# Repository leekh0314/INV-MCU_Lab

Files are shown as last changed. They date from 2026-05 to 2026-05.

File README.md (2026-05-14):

# INV-MCU_Lab

> **Gasoline Generator Digital Inverter Development Kit**  
> **汽油发电机数字逆变器开发套件**

INV-MCU_Lab 是一个面向工程学习、技术研究、项目复盘和方案验证的汽油发电机数字逆变器开源开发套件。

本项目围绕一套真实的汽油发电机数字逆变器软硬件系统展开，内容覆盖 MCU 控制软件、硬件参考资料、技术文档和测试报告，重点展示 MCU 在汽油发电机数字逆变器中的控制、采样、保护、调试和系统协同作用。

> **重要说明**  
> 虽然本项目名称中使用“开发套件”，但它不是一个建议直接量产的商业成品方案，也不是一个面向零基础用户的直接上电 DIY 套件。  
> 本项目涉及高压直流母线、230V 交流输出、大功率开关器件、汽油发动机系统和复杂保护逻辑。任何硬件复刻、上电测试或商业使用都必须由具备相关经验的工程人员完成完整验证。

---

## 1. Project Name / 项目名称

```text
English Name: INV-MCU_Lab
Chinese Name: 汽油发电机数字逆变器开发套件
```

项目名称含义：

- `INV`：Inverter，逆变器；
- `MCU`：Microcontroller Unit，微控制器；
- `Lab`：Laboratory，实验室 / 开发实验平台。

因此，INV-MCU_Lab 的核心定位是：

```text
一个用于学习、研究和理解汽油发电机数字逆变器 MCU 控制系统的开源开发套件。
```

---

## 2. Project Positioning / 项目定位

INV-MCU_Lab 不是一个简单的代码仓库，而是一个围绕真实工程项目整理出来的数字逆变器开发参考包。

它的重点不是鼓励用户直接复制一台可以量产的逆变器，而是帮助工程师理解以下问题：

- MCU 如何参与汽油发电机逆变器控制；
- PWM 如何通过查表、调制和占空比更新变成 SPWM；
- ADC 采样值如何换算成真实电压、电流和母线状态；
- 数字逆变器为什么需要软启动；
- 过压、欠压、过流、过载、过温等保护逻辑如何组织；
- 发电机运行状态、母线电压、逆变输出和 MCU 控制之间如何配合；
- MCU 软件如何与驱动电路、功率器件、采样电路和保护电路协同工作；
- 工程调试中如何通过串口输出、变量观测和故障码定位问题。

本项目更适合作为：

```text
工程学习资料
数字逆变器控制参考
MCU 控制软件架构样例
汽油发电机逆变器项目复盘资料
高压功率电子项目的系统级学习案例
```

---

## 3. Open Source Scope / 开源范围

本项目计划开源范围为：

```text
C. 软件 + 硬件 + 文档 + 测试报告
```

具体包括以下几类内容。

### 3.1 Firmware / 软件源码

软件部分主要包括：

- BAT32G139 MCU 工程源码；
- 系统初始化代码；
- PWM / SPWM 输出逻辑；
- ADC 采样与数据处理；
- 母线电压采样与补偿；
- 输出电压 / 输出电流采样处理；
- 软启动控制逻辑；
- 逆变器运行状态机；
- 保护状态机；
- 故障标志管理；
- 过压、欠压、过流、过载、短路、过温等保护逻辑；
- 串口调试输出；
- 工程参数配置文件；
- 与硬件平台相关的 BSP / Driver / App 层代码。

### 3.2 Hardware / 硬件资料

硬件部分根据整理情况可能包括：

- 原理图；
- PCB 文件；
- PCB 参考图；
- BOM；
- Gerber；
- 关键功率器件说明；
- 采样电路说明；
- 驱动电路说明；
- 辅助电源说明；
- 保护电路说明；
- 硬件接口定义。

### 3.3 Documentation / 技术文档

文档部分可能包括：

- 系统框图；
- 软件架构说明；
- 控制流程说明；
- SPWM 生成说明；
- ADC 采样换算说明；
- 软启动说明；
- 保护状态机说明；
- 故障码说明；
- 串口调试协议说明；
- 调试记录；
- 项目复盘笔记；
- 已知问题说明。

### 3.4 Test Report / 测试报告

测试报告部分可能包括：

- 型式试验报告；
- 调试测试记录；
- 关键波形记录；
- 负载测试记录；
- 故障保护测试记录；
- 工程验证记录。

由于测试报告、PDF、压缩包等文件可能较大，不建议全部直接提交到 Git 仓库主分支。大文件建议通过 GitHub Releases 发布。

---

## 4. What This Project Is / 本项目是什么

INV-MCU_Lab 是：

```text
一个汽油发电机数字逆变器 MCU 控制开发套件；
一个真实工程项目的开源学习版本；
一个用于理解数字逆变器软硬件协同的参考项目；
一个包含软件、硬件、文档和测试资料的系统级学习案例。
```

本项目可以帮助使用者学习：

- 汽油发电机逆变器的基本系统构成；
- MCU 在逆变器中的作用；
- SPWM 与功率桥之间的关系；
- ADC 采样与实际电气量之间的换算；
- 软件保护逻辑如何与硬件保护配合；
- 故障标志如何设计；
- 状态机如何组织；
- 串口调试如何服务于真实项目排障；
- 软件、硬件、功率器件和测试方法之间的关系。

---

## 5. What This Project Is Not / 本项目不是什么

为了避免误解，INV-MCU_Lab 明确不是以下内容。

### 5.1 不是直接量产方案

本项目虽然包含软件、硬件、文档和测试报告，但开源版本仍然仅作为学习、研究和工程参考使用。

不建议未经完整验证、安规评估、EMC 测试、可靠性测试、长时间负载测试和生产一致性验证，直接用于商业量产。

### 5.2 不是零基础 DIY 套件

本项目涉及高压、大功率和汽油发电机系统，不适合没有电力电子经验、没有隔离测试设备、没有示波器和差分探头经验的用户直接复刻或上电。

### 5.3 不是安全认证过的产品

本项目本身不代表已经通过任何国家或地区的安全认证、EMC 认证、能效认证、环保认证或产品合规认证。

### 5.4 不是商业技术支持服务

本项目以开源资料形式提供。作者不承诺提供商业级技术支持、定制开发、远程调试、量产问题兜底或售后服务。

### 5.5 不是第三方软件 / 工具的再分发仓库

本项目不会提供商业软件安装包、破解工具、注册机、授权文件或未经许可的第三方资料。

如果项目需要 Keil、芯片 Pack、串口工具、VOFA+、烧录工具等，请使用者自行从官方渠道获取。

---

## 6. Commercial Use Boundary / 商用边界

本项目允许用于：

```text
学习
研究
技术交流
工程参考
个人实验
非商业项目验证
```

本项目不建议直接用于：

```text
商业量产
客户项目直接交付
未验证的整机产品
面向普通用户销售的成品设备
绕过安全认证的商业应用
```

如果你希望将本项目用于商业产品、批量生产或客户项目，请务必自行完成以下工作：

- 完整硬件设计复核；
- 软件代码审查；
- 控制参数重新标定；
- 采样系数重新校准；
- 保护阈值重新确认；
- 功率器件选型验证；
- 热设计验证；
- 安规设计；
- EMC 测试；
- 高低温测试；
- 老化测试；
- 满载和过载测试；
- 短路和故障注入测试；
- 发动机实际工况测试；
- 生产测试流程设计；
- 不同国家和地区的法规合规评估。

作者不对任何直接或间接商业使用结果承担责任。

---

## 7. Technical Scope / 技术范围边界

本项目重点关注以下内容：

```text
MCU 控制逻辑
数字逆变器软件架构
SPWM 生成
ADC 采样与换算
母线电压处理
软启动控制
保护状态机
故障标志管理
串口调试
汽油发电机逆变器系统级理解
```

本项目不重点解决以下问题：

```text
最终量产设计
批量生产工艺
安规认证
EMC 认证
整机结构设计
散热器批量制造
生产测试工装
商业售后体系
不同地区法规认证
直接可销售成品设计
```

---

## 8. Hardware Safety Boundary / 硬件安全边界

本项目涉及的硬件系统可能包含：

- 高压直流母线；
- 230V AC 逆变输出；
- 大功率 MOSFET / IGBT / 驱动电路；
- 电压采样和电流采样电路；
- 汽油发动机发电绕组；
- 辅助电源；
- 继电器、风扇、保护电路；
- 散热器和高温功率器件。

错误操作可能导致：

- 触电；
- 功率器件炸裂；
- PCB 烧毁；
- 火灾；
- 发电机损坏；
- 测试仪器损坏；
- 人身伤害。

使用者在任何上电测试前，必须自行准备并确认：

- 隔离电源；
- 差分探头；
- 示波器安全接法；
- 限流措施；
- 保险丝或断路保护；
- 电子负载或合适负载；
- 绝缘防护；
- 紧急断电措施；
- 高压测试安全区域；
- 足够的电力电子和嵌入式调试经验。

---

## 9. Suggested Audience / 适合人群

本项目适合：

- 嵌入式工程师；
- 电力电子工程师；
- 汽油发电机逆变器研发人员；
- 想学习 SPWM、ADC 采样、保护状态机的工程人员；
- 想通过真实项目理解 MCU 如何控制功率硬件的学习者；
- 对数字逆变器控制软件架构感兴趣的人；
- 希望研究汽油发电机逆变器系统构成的人。

本项目不适合：

- 完全没有高压电路经验的初学者；
- 只想找一个直接复制量产方案的人；
- 没有示波器、隔离设备、负载设备的用户；
- 不理解高压大功率风险的用户；
- 希望绕过工程验证直接销售产品的人。

---

## 10. Main Features / 主要功能模块

当前项目重点覆盖以下功能模块：

- MCU system initialization；
- PWM / SPWM generation；
- ADC sampling；
- DC bus voltage processing；
- AC output voltage processing；
- AC output current processing；
- soft-start control；
- inverter state machine；
- protection state machine；
- fault flag management；
- overload protection logic；
- short-circuit protection logic；
- over-voltage and under-voltage protection logic；
- UART debug output；
- engineering parameter configuration；
- generator inverter system analysis notes。

---

## 11. Repository Structure / 仓库目录结构

建议仓库结构如下：

```text
INV-MCU_Lab/
│
├─ firmware/
│  └─ INV-MCU_Lab/
│     ├─ App/
│     ├─ BSP/
│     ├─ Driver/
│     ├─ User/
│     └─ README.md
│
├─ hardware/
│  ├─ schematic/
│  ├─ pcb/
│  ├─ bom/
│  ├─ gerber/
│  └─ README.md
│
├─ docs/
│  ├─ architecture/
│  ├─ debug_notes/
│  ├─ test_report/
│  └─ README.md
│
├─ tools/
│  ├─ scripts/
│  └─ README.md
│
├─ release_assets/
│  └─ local_only_not_committed/
│
├─ README.md
├─ LICENSE
├─ NOTICE.md
├─ DISCLAIMER.md
└─ .gitignore
```

目录说明：

- `firmware/`：MCU 源码、Keil 工程、驱动层和应用层代码；
- `hardware/`：原理图、PCB、BOM、Gerber 和硬件说明；
- `docs/`：系统说明、调试记录、框图、测试报告说明和技术文档；
- `tools/`：工具使用说明和可公开脚本；
- `release_assets/`：本地临时目录，不提交到 Git 仓库，用于整理大 PDF、压缩包和发布附件。

---

## 12. Release Downloads / 发布附件下载

Large files, tool packages and release assets are available from GitHub Releases.

大文件、工具包和发布附件请从 GitHub Releases 页面下载。

Release page:

```text
https://github.com/leekh0314/INV-MCU_Lab/releases
```

---

## 13. Development Environment / 开发环境

当前项目可能涉及以下开发环境：

```text
MCU: BAT32G139
IDE: Keil MDK
Language: C
Application: 3KW / 230V gasoline generator digital inverter
```

具体编译器版本、芯片 Pack、工程配置和烧录说明，应在 `firmware/BAT32G139/README.md` 中进一步说明。

---

## 14. Build and Debug / 编译与调试

建议后续在固件目录中补充以下内容：

- Keil 工程打开方法；
- 编译器版本要求；
- 芯片 Pack 安装说明；
- 下载器 / 烧录器说明；
- 串口调试波特率；
- 串口调试协议；
- 调试变量说明；
- 常见编译错误；
- 常见硬件调试注意事项；
- 上电前检查清单。

---

## 15. Documentation Plan / 文档计划

后续文档可以按以下主题逐步补充：

```text
01_system_overview.md
02_pwm_spwm.md
03_adc_sampling.md
04_soft_start.md
05_protection_state_machine.md
06_uart_debug.md
07_fault_code.md
08_hardware_overview.md
09_test_report_notes.md
10_known_issues.md
```

---

## 16. Known Risks / 已知风险

本项目至少存在以下风险：

- 不同硬件版本之间参数可能不完全一致；
- 不同功率器件、采样电阻、母线电压和驱动电路会影响控制参数；
- 软件保护阈值必须结合实际硬件重新校准；
- ADC 换算系数需要根据实际采样电路确认；
- PWM 死区、驱动逻辑和功率器件参数必须严格匹配；
- 直接照搬源码可能导致输出异常、器件损坏或安全事故；
- 文档和代码可能存在未完全同步的地方；
- 测试报告中的结论不能自动等同于所有复刻硬件都能达到相同结果；
- 本项目不能替代完整的产品认证和量产验证流程。

---

## 17. Contribution / 贡献方式

欢迎提交以下类型的贡献：

- 文档修正；
- 注释补充；
- 编译问题修复；
- 模块化改进；
- 调试记录补充；
- 框图和流程图补充；
- 安全警告补充；
- issue 反馈；
- 代码可读性改进。

不建议提交以下内容：

- 商业软件安装包；
- 破解工具；
- 未授权数据手册；
- 与项目无关的大文件；
- 未经验证的危险硬件修改；
- 删除安全保护逻辑的修改；
- 绕过保护机制的修改；
- 不说明风险的参数改动。

---

## 18. License / 开源协议

软件源码：MIT License
硬件资料：CERN-OHL-P
文档和测试报告：CC BY 4.0

---

## 19. Disclaimer / 免责声明

This project is provided for learning, research and engineering reference only.

本项目仅用于学习、研究和工程参考。

The author does not guarantee that this project is suitable for direct production, commercial use or direct hardware replication.

作者不保证本项目适合直接量产、商业使用或直接硬件复刻。

This project involves high voltage, high current, power inverter hardware and gasoline generator systems. Incorrect use may cause electric shock, fire, equipment damage or personal injury.

本项目涉及高压、大电流、功率逆变硬件和汽油发电机系统。错误使用可能导致触电、火灾、设备损坏或人身伤害。

Any use of this project is at your own risk.

使用本项目所产生的一切风险由使用者自行承担。

---

## 20. Recommended First Reading Order / 推荐阅读顺序

如果你是第一次接触本项目，建议按以下顺序阅读：

```text
1. README.md
2. DISCLAIMER.md
3. docs/architecture/system_overview.md
4. firmware/BAT32G139/README.md
5. docs/debug_notes/
6. hardware/README.md
7. docs/test_report/
```

---

## 21. Project Status / 项目状态

当前项目处于开源整理阶段。

后续将逐步补充：

- 更清晰的代码结构说明；
- 系统框图；
- SPWM 控制说明；
- ADC 采样说明；
- 保护状态机说明；
- 串口调试协议说明；
- 硬件资料整理；
- 测试报告和调试记录；
- Release 附件说明；
- 上电测试安全清单。

---

## 22. Final Note / 最后说明

INV-MCU_Lab 的核心价值不是鼓励用户直接复制一台逆变器，而是通过一套接近真实工程的软硬件资料，帮助工程师理解：

```text
MCU 如何参与汽油发电机数字逆变器的控制、采样、保护、调试和系统协同。
```

如果你只是想学习数字逆变器的 MCU 控制逻辑，本项目可以作为参考。

如果你想基于本项目制作真实硬件或商业产品，请务必重新完成完整的工程验证、安全评估和合规测试。

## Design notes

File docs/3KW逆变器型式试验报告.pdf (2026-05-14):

第1页 共 14 页

# 型 式 试 验 报 告

型式试验报告编号：
型式试验报总页数： 共 13 页

产 品 名 称：逆变器

产 品 型 号：

生 产 单 位：

编 | 制：
审 | 核：
批 | 准：
签发日期： | 年 | 月 | 日

第2页 共 14 页

# 检验报告

产品名称 | 逆变器 | 型 号 | 3KW-230V-50HZ | 备 注
检验目的 | 评价逆变器外观
检验项目 | 外观检查
检验依据 | 逆变器通用型式试验基准
技 术 要 求 | 逆变器的外表面清洁、标志清晰、封装完好。
检 验 方 法 | 目测

检 验 验 结 果

项 目 | 技术要求 | 1# | 2# | 3# | 4# | 5#
外 观 | 逆变器的外表面清洁、标志 清晰、封装完好 | OK | OK

第3页 共 14 页

# 检验报告

产品名称 | 逆变器 | 型 号 | 3KW-230V-50HZ | 备 注
检验目的 | 检查逆变器绝缘电阻
检验项目 | 绝缘电阻检查
检验依据 | 逆变器通用型式试验基准
技 术 要 求 | 逆变器外壳与交流输出端能承受 1500VAC 电压 5 秒不损坏且漏电流小于 5mA。
检 验 方 法 | 使用专用绝缘电阻耐压测试仪，电压调制 1500VAC，黑色表笔与逆变器外壳连接，红色表笔与逆 变器交流输出连接，按下测试按钮测试

检 验 验 结 果

项 目 | 技术要求 | 1# | 2# | 3# | 4# | 5#
绝缘电阻 | 漏电流≤5mA

第4页 共 14 页

# 检验报告

产品名称 | 逆变器 | 型 号 | 3KW-230V-50HZ | 备 注
检验目的 | 考核逆变器调速性能是否在技术要求范围内
检验项目 | 调速性能检查
检验依据 | 逆变器通用型式试验基准
技 术 要 求 | 1. 逆变器性能测试在常温环境条件下进行： 2. 逆变器能应符合下表的规定：
项 目 | 技术要求
空载转速（节能模式） | 2800±100r/min
空载转速（非节能模式） | 3400±100r/min
满载转速 | 3600±100r/min

检
验
方
法

将逆变器与适配发电机组连接，按上述技术要求进行检测。

检
验
结
果
项 目 | 技术要求 | 1# | 2#
空载转速（节能模式） | 2850±100r/min | 2840-2870 | 2840-2870
空载转速（非节能模式） | 3400±100r/min | 3370-3390 | 3370-3380
满载转速 | 3450±100r/min | 3450-3480 | 3450-3470

第5页 共 14 页

# 试验报告

产品名称 | 逆变器 | 型 号 | 3KW-230V-50HZ | 备 注
试验目的 | 考核逆变器负载能力
试验项目 | 带阻性负载
试验依据 | 逆变器通用型式试验基准

技 术 要 求

负载 比例 | 视在功率 （VA） | 测试标准
最高电 压 V | 最低电 压 V | 电流 A | 功率因素 | 频率（HZ） | THD ％
0％ | 0 | 233 | 229 | 0 | 1 | 50.0±0.1 | ≤3%
25％ | 800 | 233 | 229 | 3.5±0.5 | 1 | 50.0±0.1 | ≤3%
50％ | 1600 | 232 | 228 | 7±0.5 | 1 | 50.0±0.1 | ≤3%
75％ | 2400 | 231 | 227 | 10.5±0.5 | 1 | 50.0±0.1 | ≤3%
100％ | 3200 | 230 | 226 | 14±0.5 | 1 | 50.0±0.1 | ≤3%
110％ | 3520
试 验 方 法 | 检验方法：将安装有测试逆变器的发电机组与负载柜连接，使用相应设备测试，记录数据

试
验
结
果
负载 比例 | 视在功率 （VA） | 测试标准 | 功率 因数 | 测试结果
最高 电压 234V | 最低 电压 226V | 电流 A | | 最高电 压 V | 最低 电压 V | 电 流 A | 频率 （HZ） | THD ％
0％ | | 233 | 229 | 0 | 1 | 231.1 | 231
25％ | 800 | 233 | 229 | 3.5± 0.5 | 1 | 231.2 | 231.1 | 3.4 | 50.04
50％ | 1600 | 232 | 228 | 7± 0.5 | 1 | 229.9 | 229.8 | 6.9 7 | 50.03
75％ | 2400 | 231 | 227 | 10.5 ±0.5 | 1 | 228.4 | 228.3 | 10. 73 | 50.03
100％ | 3200 | 230 | 226 | 14± 0.5 | 1 | 226.5 | 226.4 | 14. 28 | 50.03
110％ | 3520

第6页 共 14 页

# 试验报告

产品名称 | 逆变器 | 型 号 | 3KW-230V-50HZ | 备 注
试验目的 | 考核逆变器负载能力
试验项目 | 带非线性负载
试验依据 | 逆变器通用型式试验基准

技 术 要 求

负载 比例 | 视在功率 （VA） | 测试标准
最高电 压 V | 最低电 压 V | 电流 A | 功率因素 | 频率（HZ） | THD ％
0％ | 0 | 233 | 229 | 0 | 0.8 | 50.0±0.1 | ≤6%
25％ | 800 | 233 | 229 | 3.5±0.5 | 0.8 | 50.0±0.1 | ≤6%
50％ | 1600 | 232 | 228 | 7±0.5 | 0.8 | 50.0±0.1 | ≤6%
75％ | 2400 | 231 | 227 | 10.5±0.5 | 0.8 | 50.0±0.1 | ≤6%
100％ | 3200 | 230 | 226 | 14±0.5 | 0.8 | 50.0±0.1 | ≤6%
110％ | 3520
试 验 方 法 | 检验方法：将安装有测试逆变器的发电机组与负载柜连接，使用相应设备测试，记录数据
试 验 结 果 | | 负载 比例 | 视在功率 （VA） | 测试标准 | 功率 因数 | 测试结果
最高 电压 234V | 最低 电压 226V | 电流 A | | 最高电 压 V | 最低 电压 V | 电 流 A | 频率 （HZ） | THD ％
0％ | | 233 | 229 | 0 | 0.8 | 231.1 | 231
25％ | 800 | 233 | 228 | 3.5± 0.5 | 0.8 | 229.2 | 229.1 | 3.6 5 | 50.04
50％ | 1600 | 232 | 227 | 7± 0.5 | 0.8 | 228.2 | 228.1 | 6.9 2 | 50.03
75％ | 2400 | 231 | 226 | 10.5 ±0.5 | 0.8 | 227.4 | 227.3 | 10. 57 | 50.03
100％ | 3200 | 230 | 225 | 14± 0.5 | 0.8 | 226.1 | 226.0 | 14. 32 | 50.03
110％ | 3520

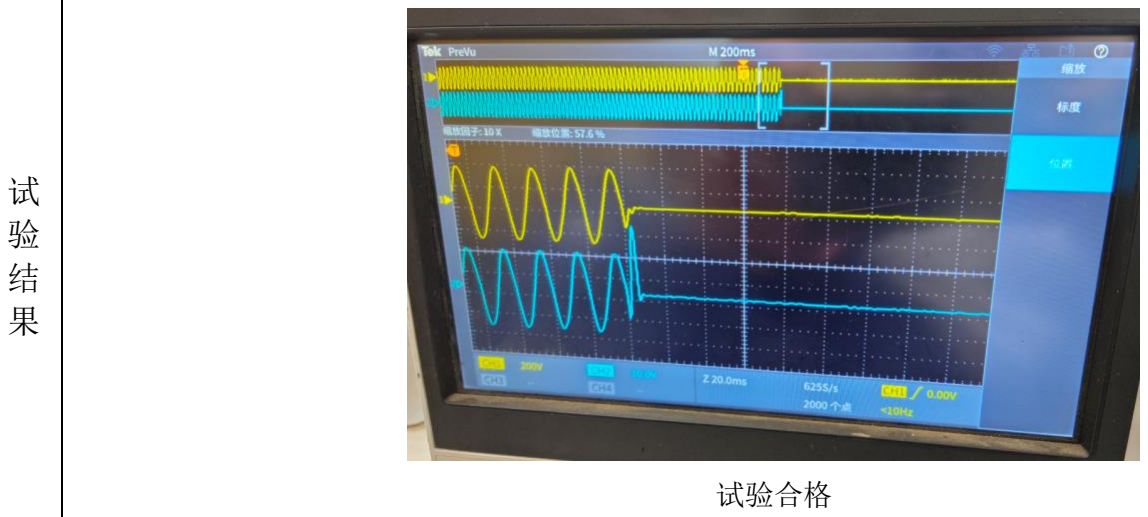
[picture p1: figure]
试验合格

第7页 共 14 页

# 试验报告

产品名称 | 逆变器 | 型 号 | 3KW-230V-50HZ | 备 注
试验目的 | 考核逆变器冲击性能
试验项目 | 短路试验
试验依据 | 逆变器通用型式试验基准
技 术 要 求 | 逆变器在额定负载下进行输出短路，连续短路 100 测逆变器无损坏
试 验 方 法 | 将测试逆变器机组与负载连接，短路 2S,断开 10S，断开过程复位逆变器，连续重复 100 次

第8页 共 14 页

# 试验报告

产品名称 | 逆变器 | 型 号 | 3KW-230V-50HZ | 备 注
试验目的 | 考核逆变器耐温性能
试验项目 | 高温试验
试验依据 | 逆变器通用型式试验基准
技 术 要 求 | 将逆变器升温至 75℃，在额定负载下工作，工作过程维持温度 75℃，连续运行 10 小时，逆变器 不损坏
试 验 方 法 | 将测试逆变器机组与负载柜连接，将逆变器升温至 75℃，加额定负载运行，过程中人为控制逆变 器外壳温度为 75℃，连续运行 10 小时，记录结果
试 验 结 果 | 高温后产品性能符合要求，试验合格

第9页 共 14 页

产品名称 | 逆变器 | 型 号 | 3KW-230V-50HZ | 备 注
试验目的 | 考核逆变器耐温性能
试验项目 | 低温试验
试验依据 | 逆变器通用型式试验基准
技 术 要 求 | 逆变器在-25℃环境下静置不少于 48 小时，逆变器能正常启动，启动后加额定负载正常工作，无 损坏
试 验 方 法 | 将逆变器在-25℃环境下静置不少于 48 小时，逆变器与机组连接，启动机组记录启动结果，加额 定负载，记录带载结果
试 验 结 果 | 试验后逆变器启动正常，试验合格

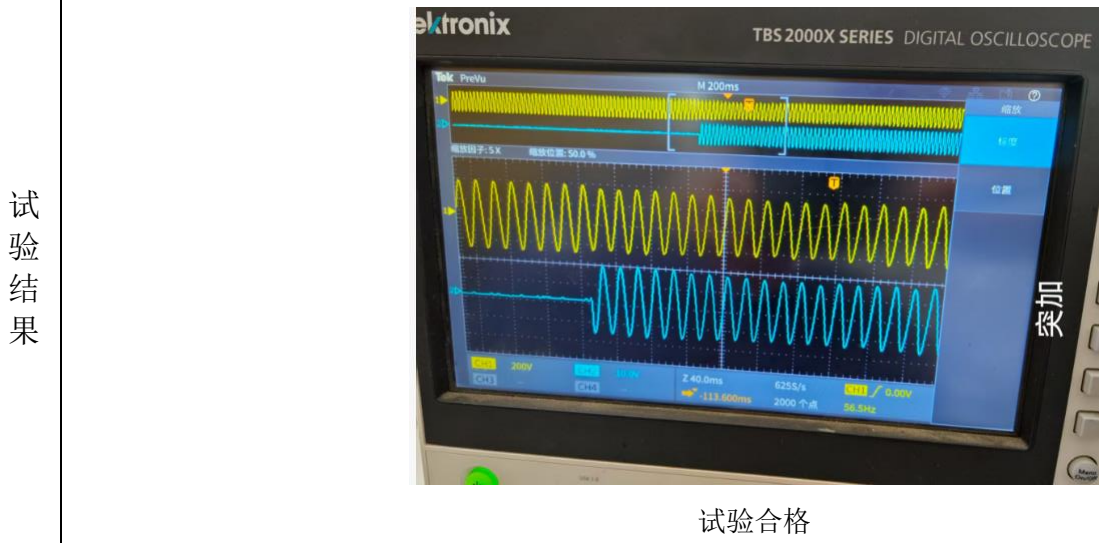
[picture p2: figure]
试验合格

第10页 共 14 页

产品名称 | 逆变器 | 型 号 | 3KW-230V-50HZ | 备 注
试验目的 | 考核逆变器冲击性能
试验项目 | 突加阻性负载试验
试验依据 | 逆变器通用型式试验基准
技 术 要 求 | 逆变器与机组连接，并于额定负载连接，突加额定阻性负载，逆变器波形正常，试验结束后逆变 器无故障，试验过程中逆变器无误保护。
试 验 方 法 | 逆变器与机组连接，并于额定负载连接，突加额定阻性负载，试验次数 100 次

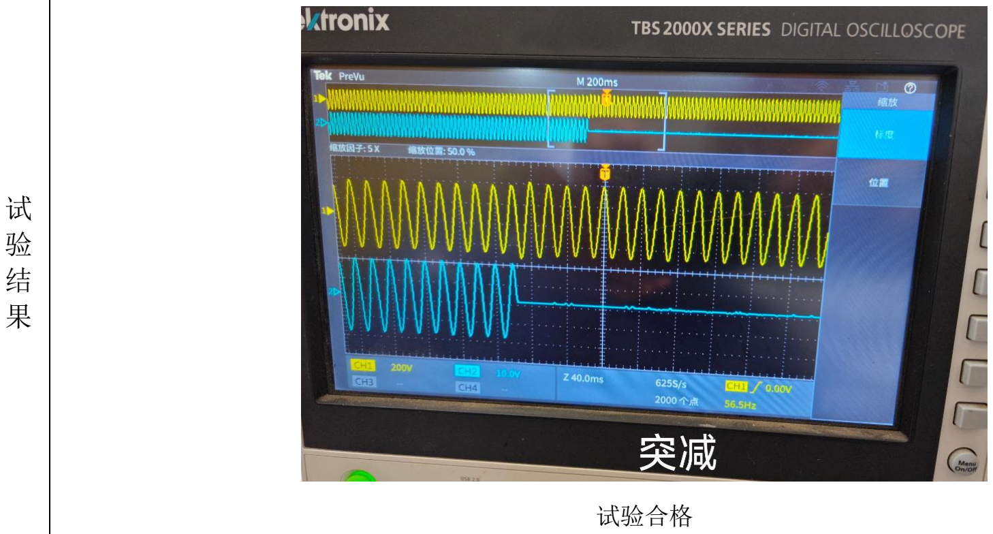
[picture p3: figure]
试验合格

第11页 共 14 页

产品名称 | 逆变器 | 型 号 | 3KW-230V-50HZ | 备 注
试验目的 | 考核逆变器冲击性能
试验项目 | 突减阻性负载试验
试验依据 | 逆变器通用型式试验基准
技 术 要 求 | 逆变器与机组连接，并于额定负载连接，逆变器满载阻性负载运行，突减去全部负载，逆变器波 形正常，试验结束后逆变器无故障，试验过程中逆变器无误保护。
试 验 方 法 | 逆变器与机组连接，并于额定负载连接并加载，逆变器满载阻性负载运行，突减负载，试验次数 100 次

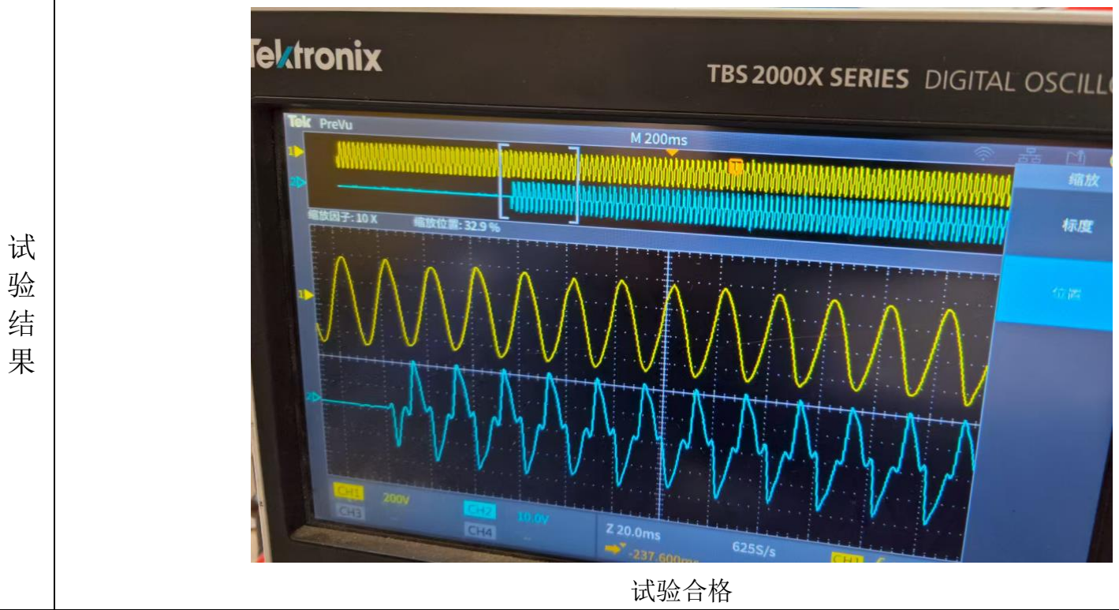
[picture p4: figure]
试验合格

第12页 共 14 页

产品名称 | 逆变器 | 型 号 | 3KW-230V-50HZ | 备 注
试验目的 | 考核逆变器冲击性能
试验项目 | 突加非线性负载试验
试验依据 | 逆变器通用型式试验基准
技 术 要 求 | 逆变器与机组连接，并于额定负载连接，突加额定非线性性负载，逆变器波形正常，试验结束后 逆变器无故障，试验过程中逆变器无误保护。
试 验 方 法 | 逆变器与机组连接，并于额定负载连接，突加额定非线性负载，试验次数 100 次

第13页 共 14 页

产品名称 | 逆变器 | 型 号 | 3KW-230V-50HZ | 备 注
试验目的 | 考核逆变器冲击性能
试验项目 | 突减非线性负载试验
试验依据 | 逆变器通用型式试验基准
技 术 要 求 | 逆变器与机组连接，并于额定负载连接，逆变器满载非线性负载运行，突减去全部负载，逆变器 波形正常，试验结束后逆变器无故障，试验过程中逆变器无误保护。
试 验 方 法 | 逆变器与机组连接，并于额定负载连接并加载，逆变器满载非线性负载运行，突减负载，试验次 数 100 次

试
验
结
果

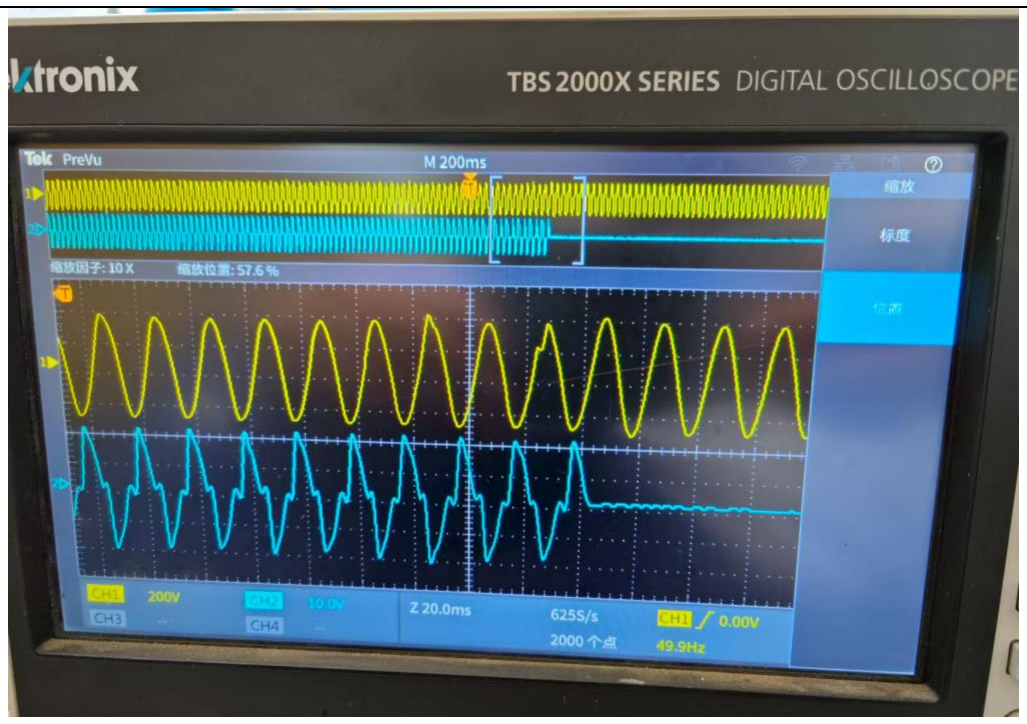
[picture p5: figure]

试验合格

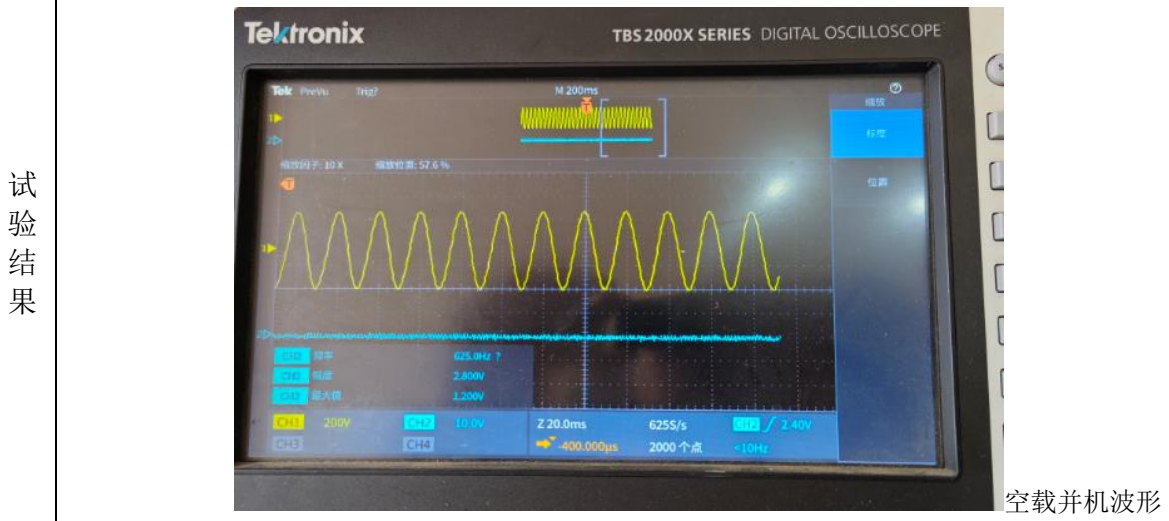
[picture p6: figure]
空载并机波形

第14页 共 14 页

产品名称 | 逆变器 | 型 号 | 3KW-230V-50HZ | 备 注
试验目的 | 考核逆变器并机性能
试验项目 | 并机环流带载试验
试验依据 | 逆变器通用型式试验基准
技 术 要 求 | 将两台逆变器连接在一起，先启动一台，启动的正常工作后，启动另一台，两台正常启动后，任 意一台无保护现象，并机环流小于 0.5A，总负载能力不低于两个单台相加负载综合的 93％
试 验 方 法 | 按上述技术要求连接逆变器，正常工作后记录数据

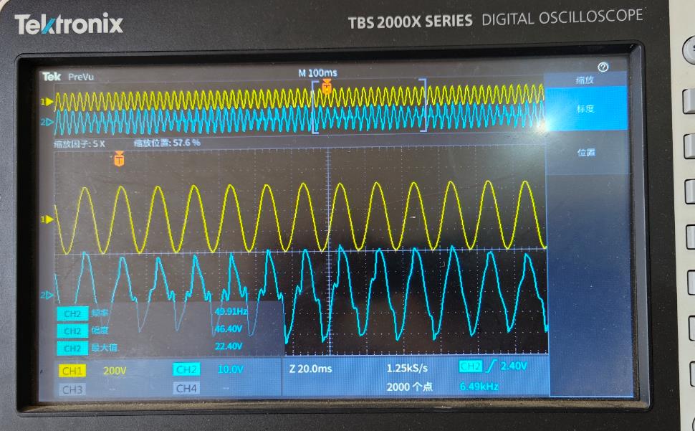
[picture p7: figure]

第15页 共 14 页

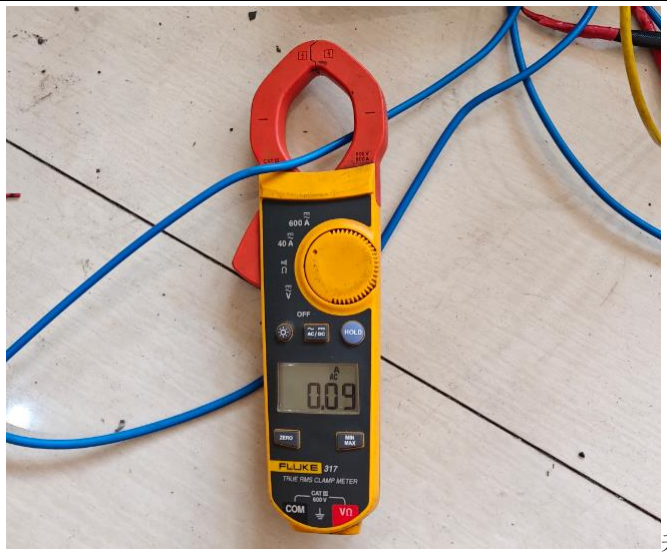
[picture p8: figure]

并机环流

并机满载波形

黄色为电压波形，绿色为电流波形
并机合格

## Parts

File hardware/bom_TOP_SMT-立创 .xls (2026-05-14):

立创商城BOM报价单
BOM配单编号： |  |  |  |  | 上传时间： |  |  |  | 1.名称释义：MPQ--最小包装量；MOQ--最小起订量； 2.匹配结果为实时查询结果，库存和价格可能会有波动。如超过24小时，请在立创商城重新匹配后下单； 3.订货商品的价格仅供参考，请提交订单后确定。 4.如有部分物料未能成功匹配，需要整单购买，请联系商城客服。
BOM名称：bom_TOP_SMT |  |  |  |  | 采购套数：
商品总价: 注：报价单总价不含待确认和无法匹配项 |  |  |  |  | 网址：
原始需求 |  |  |  |  |  |  |  |  | 匹配结果 |  |  |  |  |  |  | 订单满足
原始型号 | 原始品牌 | Footprint | Comment | C编码 | No. | Description | Designator | Quantity | 匹配结果 | 商品名称 | 型号 | 品牌 | 封装 | 参数 | 目录 | 商品编号 | 商品链接 | 渠道 | 交期 | MOQ | MPQ | 库存 | 购买数量 | 单价(RMB) | 关税税率 | 小计(RMB) | 备注
 |  | C0603 | 105 |  | 1 | 贴片 无极性电容 | C1, C6, C33, C83 | 4 | 系统匹配 | 1uF ±10% 50V | CGA0603X5R105K500JT | HRE(芯声) | 0603 | 容值：1uF 精度：±10% 额定电压：50V 温度系数：X5R | 电容 | C6119852 | https://item.szlcsc.com/7062558.html | 现货 | 4小时内发货 | 50 | 4000 | 6082200 | 50 | 0.0501 | 0 | 2.51
 |  | 1206C | 102/1KV |  | 2 | 贴片 无极性电容 | C3, C62, C63, C64, C66, C67, C68 | 7 | 系统匹配 | 1nF ±10% 1kV | 1206B102K102NT | FH(风华) | 1206 | 容值：1nF 精度：±10% 额定电压：1kV 温度系数：X7R | 电容 | C1941 | https://item.szlcsc.com/2293.html | 现货 | 4小时内发货 | 50 | 3000 | 939450 | 100 | 0.0632 | 0 | 6.32
 |  | C0603 | 104 |  | 3 | 贴片 无极性电容 | C4, C5, C8, C10, C11, C12, C16, C17, C23, C30, C36, C44, C46, C50, C71, C79, C84 | 17 | 系统匹配 | 100nF ±10% 50V | CGA0603X7R104K500JT | HRE(芯声) | 0603 | 容值：100nF 精度：±10% 额定电压：50V 温度系数：X7R | 电容 | C6119867 | https://item.szlcsc.com/7062573.html | 现货 | 4小时内发货 | 100 | 4000 | 19535300 | 200 | 0.0161 | 0 | 3.22
 |  | C0603 | 471/50V |  | 5 | 贴片 无极性电容 | C13 | 1 | 系统匹配 | 470pF ±10% 50V | 0603B471K500NT | FH(风华) | 0603 | 容值：470pF 精度：±10% 额定电压：50V 温度系数：X7R | 电容 | C1620 | https://item.szlcsc.com/1972.html | 现货 | 4小时内发货 | 100 | 4000 | 800800 | 100 | 0.0208 | 0 | 2.08
 |  | C0603 | 226 |  | 6 | 贴片 无极性电容 | C14, C25, C27, C32 | 4 | 系统匹配 | 22uF ±20% 16V | CGA0603X5R226M160JT | HRE(芯声) | 0603 | 容值：22uF 精度：±20% 额定电压：16V 温度系数：X5R | 电容 | C6119868 | https://item.szlcsc.com/7062574.html | 现货 | 4小时内发货 | 10 | 4000 | 500490 | 50 | 0.242 | 0 | 12.10
 |  | C0603 | 102 |  | 7 | 贴片 无极性电容 | C15, C18, C20, C21, C22, C26, C45, C49, C51, C54 | 10 | 系统匹配 | 1nF ±10% 50V | CC0603KRX7R9BB102 | YAGEO(国巨) | 0603 | 容值：1nF 精度：±10% 额定电压：50V 温度系数：X7R | 电容 | C100040 | https://item.szlcsc.com/101254.html | 现货 | 4小时内发货 | 100 | 4000 | 9242300 | 100 | 0.0151 | 0 | 1.51
 |  | C0603 | 103 |  | 8 | 贴片 无极性电容 | C19, C24, C28, C31, C37, C42, C47, C82 | 8 | 系统匹配 | 10nF ±10% 50V | CC0603KRX7R9BB103 | YAGEO(国巨) | 0603 | 容值：10nF 精度：±10% 额定电压：50V 温度系数：X7R | 电容 | C100042 | https://item.szlcsc.com/101256.html | 现货 | 4小时内发货 | 100 | 4000 | 4069100 | 100 | 0.0155 | 0 | 1.55
 |  | C0603 | 20pF |  | 9 | 贴片 无极性电容 | C34, C41 | 2 | 系统匹配 | 20pF ±5% 50V | CC0603JRNPO9BN200 | YAGEO(国巨) | 0603 | 容值：20pF 精度：±5% 额定电压：50V 温度系数：NP0 | 电容 | C105621 | https://item.szlcsc.com/106836.html | 现货 | 4小时内发货 | 100 | 4000 | 4229800 | 100 | 0.0189 | 0 | 1.89
 |  | C0603 | 101 |  | 10 | 贴片 无极性电容 | C35, C43, C53, C55 | 4 | 系统匹配 | 100pF ±5% 50V | CC0603JRNPO9BN101 | YAGEO(国巨) | 0603 | 容值：100pF 精度：±5% 额定电压：50V 温度系数：NP0 | 电容 | C14665 | https://item.szlcsc.com/15333.html | 现货 | 4小时内发货 | 100 | 4000 | 8312100 | 100 | 0.0175 | 0 | 1.75
 |  | C0603 | 106 |  | 11 | 贴片 无极性电容 | C40 | 1 | 系统匹配 | 10uF ±10% 10V | CGA0603X5R106K100JT | HRE(芯声) | 0603 | 容值：10uF 精度：±10% 额定电压：10V 温度系数：X5R | 电容 | C6119842 | https://item.szlcsc.com/7062548.html | 现货 | 4小时内发货 | 50 | 4000 | 2849500 | 50 | 0.05 | 0 | 2.50
 |  | 1206C | 103/50V |  | 12 | 贴片 无极性电容 | C58, C59, C60 | 3 | 系统匹配 | 10nF ±10% 50V | FCC1206B103K500DT | FOJAN(富捷) | 1206 | 容值：10nF 精度：±10% 额定电压：50V 温度系数：X7R | 电容 | C5137623 | https://item.szlcsc.com/5747075.html | 现货 | 4小时内发货 | 50 | 4000 | 651600 | 50 | 0.0655 | 0 | 3.28
 |  | 1206C | 471/1KV |  | 13 | 贴片 无极性电容 | C61, C65, C75, C76 | 4 | 系统匹配 | 470pF ±10% 1kV | 1206B471K102NT | FH(风华) | 1206 | 容值：470pF 精度：±10% 额定电压：1kV 温度系数：X7R | 电容 | C9189 | https://item.szlcsc.com/9714.html | 现货 | 4小时内发货 | 50 | 3000 | 216100 | 50 | 0.080586 | 0 | 4.03
 |  | 1206C | 225 |  | 14 | 贴片 无极性电容 | C70, C72, C73, C74, C77, C78, C80, C81 | 8 | 系统匹配 | 2.2uF ±10% 100V | CC1206KKX7R0BB225 | YAGEO(国巨) | 1206 | 容值：2.2uF 精度：±10% 额定电压：100V 温度系数：X7R | 电容 | C577211 | https://item.szlcsc.com/604702.html | 现货 | 4小时内发货 | 10 | 2000 | 310530 | 10 | 0.3512 | 0 | 3.51
 |  | SMA - AK | SS1200 |  | 15 | 贴片 二极管 | D1, D2, D4, D5, D7, D9, D26 | 7 | 系统匹配 | 电压:200V 电流:1A | SS1200 | MDD(辰达半导体) | SMA(DO-214AC) | 二极管配置：独立式 正向压降(Vf)：900mV@1A 直流反向耐压(Vr)：200V 整流电流：1A 反向电流(Ir)：100uA@200V 工作结温范围：-55℃~+150℃ 非重复峰值浪涌电流 (Ifsm)：25A | 二极管 | C64988 | https://item.szlcsc.com/66058.html | 现货 | 4小时内发货 | 20 | 5000 | 198280 | 80 | 0.20304 | 0 | 16.24
 |  | SMA - AK | US2M |  | 16 | 贴片 二极管 | D3, D6 | 2 | 系统匹配 | 耐压:1000V 电流:2A 反向恢复时间：75ns | US2M | R+O(宏嘉诚) | SMA(DO-214AC) | 二极管配置：1个独立式 正向压降(Vf)：1.7V@2A 直流反向耐压(Vr)：1kV 整流电流：2A 反向电流(Ir)：2uA@1000V 反向恢复时间(Trr)：75ns 工作结温范围：-55℃~+150℃ 非重复峰值浪涌电流 (Ifsm)：50A | 二极管 | C18199132 | https://item.szlcsc.com/19354364.html | 现货 | 4小时内发货 | 50 | 5000 | 80550 | 50 | 0.1164 | 0 | 5.82
 |  | SOD-123F | 1N4148 |  | 17 | 贴片 二极管 | D8, D14, D19, D21, D22, D23, D24, D25, D27 | 9 | 人工匹配 | 100V 150mA | 1N4148W | R+O(宏嘉诚) | SOD-123 | 二极管配置：独立式 耗散功率(Pd)：400mW 整流电流：150mA 直流反向耐压(Vr)：100V 正向压降(Vf)：1.25V@150mA 非重复峰值浪涌电流 (Ifsm)：2A 反向电流(Ir)：1uA@75V 反向恢复时间(Trr)：4ns 工作结温范围：-55℃~+150℃ | 二极管 | C7420318 | https://item.szlcsc.com/8397140.html | 现货 | 4小时内发货 | 100 | 3000 | 3172200 | 100 | 0.0348 | 0 | 3.48
 |  | SOT-23 | BAV99 |  | 18 | 贴片串联双二极管 | D10, D13, D18, Q4, Q5, Q6, Q7 | 7 | 系统匹配 | 70V 200mA | BAV99 | R+O(宏嘉诚) | SOT-23 | 二极管配置：1对串联式 耗散功率(Pd)：225mW 整流电流：200mA 直流反向耐压(Vr)：70V 正向压降(Vf)：1.25V@150mA 非重复峰值浪涌电流 (Ifsm)：2A 反向电流(Ir)：2.5uA@75V 反向恢复时间(Trr)：4ns 工作结温范围：-55℃~+150℃ | 二极管 | C7420336 | https://item.szlcsc.com/8397158.html | 现货 | 4小时内发货 | 50 | 3000 | 715600 | 100 | 0.055 | 0 | 5.50
 |  | SMA - AK | ES1J |  | 19 | 贴片 二极管 | D20 | 1 | 系统匹配 | 耐压:600V 电流:1A 反向恢复时间：35ns | ES1J | R+O(宏嘉诚) | SMA(DO-214AC) | 二极管配置：1个独立式 正向压降(Vf)：1.7V@1A 直流反向耐压(Vr)：600V 整流电流：1A 反向电流(Ir)：2uA@600V 反向恢复时间(Trr)：35ns 工作结温范围：-55℃~+150℃ 非重复峰值浪涌电流 (Ifsm)：30A | 二极管 | C18199159 | https://item.szlcsc.com/19354391.html | 现货 | 4小时内发货 | 50 | 5000 | 307750 | 50 | 0.0665 | 0 | 3.33
 |  | SOP-4-P1.27 | LTV-217-C-G |  | 20 | 光耦 | PQ1, PQ2 | 2 | 系统匹配 | DC输入 隔离电压(rms):3750V | LTV-217-C-G | LITEON(光宝) | SOP-4-175mil | 输入类型：DC 输出类型：光电三极管 正向压降(Vf)：1.2V 输出电流：50mA 隔离电压(Vrms)：3.75kV 直流反向耐压(Vr)：6V 负载电压：80V 输出通道数：1 集射极饱和电压(VCE(sat))：400mV@2.4mA,8mA 上升时间(tr)：2us@2mA,100Ω 下降时间：3us 工作温度：-55℃~+110℃ 电流传输比(CTR)最小值：50% 电流传输比(CTR)最大值/饱和值：600% 总功耗(Pd)：200mW 正向电流(If)：50mA | 光耦 | C123196 | https://item.szlcsc.com/124466.html | 订货 | 预估7-10个工作日 | 5 | 3000 | 0 | 20 | 0.491 | 0 | 9.82
 |  | S8050 | S9013 |  | 21 | 三极管 | Q2, Q3, Q17, Q18, Q19 | 5 | 系统匹配 | hFE:200-350，丝印:J3Y NPN 500mA 25V | S8050 | R+O(宏嘉诚) | SOT-23 | 晶体管类型：NPN 集电极电流(Ic)：500mA 集射极击穿电压(Vceo)：25V 耗散功率(Pd)：300mW 直流电流增益(hFE)：120 特征频率(fT)：100MHz 集电极截止电流(Icbo)：100nA 集射极饱和电压(VCE(sat))：600mV 工作温度：-55℃~+150℃ 射基极击穿电压(Vebo)：5V 数量：1个NPN hFE:200-350，丝印:J3Y | 三极管/MOS管/晶体管 | C20069125 | https://item.szlcsc.com/21397163.html | 现货 | 4小时内发货 | 50 | 3000 | 636500 | 50 | 0.0638 | 0 | 3.19
 |  | SOT-23 | S9013 |  | 22 | 三极管 | Q15, Q16 | 2 | 系统匹配 | NPN 电流:0.5A 电压:25V | S9013 | MDD(辰达半导体) | SOT-23 | 晶体管类型：NPN 集电极电流(Ic)：500mA 集射极击穿电压(Vceo)：25V 耗散功率(Pd)：300mW 直流电流增益(hFE)：400 特征频率(fT)：150MHz 集电极截止电流(Icbo)：100nA 集射极饱和电压(VCE(sat))：600mV 工作温度：-55℃~+150℃ 射基极击穿电压(Vebo)：5V 数量：1个NPN | 三极管/MOS管/晶体管 | C431712 | https://item.szlcsc.com/428177.html | 现货 | 4小时内发货 | 50 | 3000 | 433550 | 50 | 0.067872 | 0 | 3.39
 |  | 0603R | 10K |  | 23 | 贴片 电阻器 | R1, R11, R17, R20, R22, R24, R37, R50, R53, R55, R57, R58, R59, R77, R89, R92, R110, R127, R141 | 19 | 系统匹配 | 10kΩ ±1% 100mW 厚膜电阻 | FRC0603F1002TS | FOJAN(富捷) | 0603 | 电阻类型：厚膜电阻 阻值：10kΩ 精度：±1% 功率：100mW 工作电压：75V 温度系数：±100ppm/℃ 工作温度：-55℃~+155℃ | 电阻 | C2906982 | https://item.szlcsc.com/3180495.html | 现货 | 4小时内发货 | 100 | 5000 | 15560500 | 200 | 0.0063 | 0 | 1.26
 |  | 0603R | 3K |  | 24 | 贴片 电阻器 | R2, R12, R18, R23, R26, R29, R51, R61, R69, R135 | 10 | 系统匹配 | 3kΩ ±1% 100mW 厚膜电阻 | 0603WAF3001T5E | UNI-ROYAL(厚声) | 0603 | 电阻类型：厚膜电阻 阻值：3kΩ 精度：±1% 功率：100mW 工作电压：75V 温度系数：±100ppm/℃ 工作温度：-55℃~+155℃ | 电阻 | C4211 | https://item.szlcsc.com/4618.html | 现货 | 4小时内发货 | 100 | 5000 | 1806400 | 100 | 0.0083 | 0 | 0.83
 |  | 0603R | 1K |  | 25 | 贴片 电阻器 | R3, R4, R5, R7, R30, R41, R42, R43, R47, R49, R54, R62, R63, R65, R74, R86, R90, R111, R128, R133, R136, R137, R138, R139, R143 | 25 | 系统匹配 | 1kΩ ±1% 100mW 厚膜电阻 | FRC0603F1001TS | FOJAN(富捷) | 0603 | 电阻类型：厚膜电阻 阻值：1kΩ 精度：±1% 功率：100mW 工作电压：75V 温度系数：±100ppm/℃ 工作温度：-55℃~+155℃ | 电阻 | C2907002 | https://item.szlcsc.com/3180515.html | 现货 | 4小时内发货 | 100 | 5000 | 5531400 | 300 | 0.0069 | 0 | 2.07
 |  | 1206R | 10R/1% |  | 26 | 贴片 电阻器 | R6 | 1 | 系统匹配 | 10Ω ±1% 250mW 厚膜电阻 | 1206W4F100JT5E | UNI-ROYAL(厚声) | 1206 | 电阻类型：厚膜电阻 阻值：10Ω 精度：±1% 功率：250mW 工作电压：200V 温度系数：±400ppm/℃ 工作温度：-55℃~+155℃ | 电阻 | C17903 | https://item.szlcsc.com/18591.html | 现货 | 4小时内发货 | 100 | 5000 | 267600 | 100 | 0.0252 | 0 | 2.52
 |  | 0603R | 100K |  | 27 | 贴片 电阻器 | R8, R13 | 2 | 系统匹配 | 100kΩ ±1% 100mW 厚膜电阻 | 0603WAF1003T5E | UNI-ROYAL(厚声) | 0603 | 电阻类型：厚膜电阻 阻值：100kΩ 精度：±1% 功率：100mW 工作电压：75V 温度系数：±100ppm/℃ 工作温度：-55℃~+155℃ | 电阻 | C25803 | https://item.szlcsc.com/26546.html | 现货 | 4小时内发货 | 100 | 5000 | 3425800 | 100 | 0.0107 | 0 | 1.07
 |  | 1206R | 1.5K 1% |  | 28 | 贴片 电阻器 | R9, R15 | 2 | 系统匹配 | 1.5kΩ ±1% 250mW 厚膜电阻 | 1206W4F1501T5E | UNI-ROYAL(厚声) | 1206 | 电阻类型：厚膜电阻 阻值：1.5kΩ 精度：±1% 功率：250mW 工作电压：200V 温度系数：±100ppm/℃ 工作温度：-55℃~+155℃ | 电阻 | C26030 | https://item.szlcsc.com/26773.html | 现货 | 4小时内发货 | 100 | 5000 | 29600 | 100 | 0.022374 | 0 | 2.24
 |  | 1206R | 10K |  | 29 | 贴片 电阻器 | R10, R14 | 2 | 系统匹配 | 10kΩ ±1% 250mW 厚膜电阻 | 1206W4F1002T5E | UNI-ROYAL(厚声) | 1206 | 电阻类型：厚膜电阻 阻值：10kΩ 精度：±1% 功率：250mW 工作电压：200V 温度系数：±100ppm/℃ 工作温度：-55℃~+155℃ | 电阻 | C17902 | https://item.szlcsc.com/18590.html | 现货 | 4小时内发货 | 100 | 5000 | 265800 | 100 | 0.0301 | 0 | 3.01
 |  | 1206R | 5.1R |  | 30 | 贴片 电阻器 | R16, R19, R150 | 3 | 系统匹配 | 5.1Ω ±1% 250mW 厚膜电阻 | FRC1206F5R10TS | FOJAN(富捷) | 1206 | 电阻类型：厚膜电阻 阻值：5.1Ω 精度：±1% 功率：250mW 工作电压：200V 温度系数：±200ppm/℃ 工作温度：-55℃~+155℃ | 电阻 | C2933736 | https://item.szlcsc.com/3279838.html | 现货 | 4小时内发货 | 100 | 5000 | 259900 | 100 | 0.0293 | 0 | 2.93
 |  | 0603R | 30K |  | 31 | 贴片 电阻器 | R21, R28, R52, R113, R114, R129, R130 | 7 | 系统匹配 | 30kΩ ±1% 100mW 厚膜电阻 | FRC0603F3002TS | FOJAN(富捷) | 0603 | 电阻类型：厚膜电阻 阻值：30kΩ 精度：±1% 功率：100mW 工作电压：75V 温度系数：±100ppm/℃ 工作温度：-55℃~+155℃ | 电阻 | C2907025 | https://item.szlcsc.com/3180538.html | 现货 | 4小时内发货 | 100 | 5000 | 1860500 | 100 | 0.0068 | 0 | 0.68
 |  | 1206R | 100R |  | 32 | 贴片 电阻器 | R25 | 1 | 系统匹配 | 100Ω ±1% 250mW 厚膜电阻 | 1206W4F1000T5E | UNI-ROYAL(厚声) | 1206 | 电阻类型：厚膜电阻 阻值：100Ω 精度：±1% 功率：250mW 工作电压：200V 温度系数：±100ppm/℃ 工作温度：-55℃~+155℃ | 电阻 | C17901 | https://item.szlcsc.com/18589.html | 现货 | 4小时内发货 | 100 | 5000 | 560800 | 100 | 0.0286 | 0 | 2.86
 |  | 0603R | 5.1M |  | 33 | 贴片 电阻器 | R27, R66, R73 | 3 | 系统匹配 | 5.1MΩ ±5% 100mW 厚膜电阻 | FRC0603J515 TS | FOJAN(富捷) | 0603 | 电阻类型：厚膜电阻 阻值：5.1MΩ 精度：±5% 功率：100mW 工作电压：75V 温度系数：±100ppm/℃ 工作温度：-55℃~+155℃ | 电阻 | C2907175 | https://item.szlcsc.com/3180688.html | 现货 | 4小时内发货 | 100 | 5000 | 74600 | 100 | 0.0052 | 0 | 0.52
 |  | 1206R | 0.5R 1% |  | 34 | 贴片 电阻器 | R31, R32 | 2 | 系统匹配 | 500mΩ ±1% 250mW 厚膜电阻 | 1206W4F500LT5E | UNI-ROYAL(厚声) | 1206 | 电阻类型：厚膜电阻 阻值：500mΩ 精度：±1% 功率：250mW 工作电压：200V 温度系数：±800ppm/℃ 工作温度：-55℃~+155℃ | 电阻 | C25340 | https://item.szlcsc.com/26083.html | 现货 | 4小时内发货 | 50 | 5000 | 248750 | 50 | 0.040887 | 0 | 2.04
 |  | 0603R | 2.7K |  | 35 | 贴片 电阻器 | R33, R56 | 2 | 系统匹配 | 2.7kΩ ±1% 100mW 厚膜电阻 | FRC0603F2701TS | FOJAN(富捷) | 0603 | 电阻类型：厚膜电阻 阻值：2.7kΩ 精度：±1% 功率：100mW 工作电压：75V 温度系数：±100ppm/℃ 工作温度：-55℃~+155℃ | 电阻 | C2907008 | https://item.szlcsc.com/3180521.html | 现货 | 4小时内发货 | 100 | 5000 | 735500 | 100 | 0.0064 | 0 | 0.64
 |  | 0603R | 50K |  | 36 | 贴片 电阻器 | R34, R48 | 2 | 系统匹配 | 薄膜电阻 50kΩ ±0.1% 100mW | RT0603BRD0750KL | YAGEO(国巨) | 0603 | 电阻类型：薄膜电阻 阻值：50kΩ 精度：±0.1% 功率：100mW 工作电压：75V 温度系数：±25ppm/℃ 工作温度：-55℃~+155℃ | 电阻 | C861451 | https://item.szlcsc.com/921789.html | 现货 | 4小时内发货 | 20 | 5000 | 243040 | 20 | 0.134 | 0 | 2.68
 |  | 0603R | 2K |  | 37 | 贴片 电阻器 | R35, R70, R76, R83, R88, R91, R131 | 7 | 系统匹配 | 2kΩ ±1% 100mW 厚膜电阻 | 0603WAF2001T5E | UNI-ROYAL(厚声) | 0603 | 电阻类型：厚膜电阻 阻值：2kΩ 精度：±1% 功率：100mW 工作电压：75V 温度系数：±100ppm/℃ 工作温度：-55℃~+155℃ | 电阻 | C22975 | https://item.szlcsc.com/23702.html | 现货 | 4小时内发货 | 100 | 5000 | 1302000 | 100 | 0.0103 | 0 | 1.03
 |  | 0603R | 1.8K |  | 38 | 贴片 电阻器 | R71,R79, | 2 | 系统匹配 | 1.8kΩ ±1% 100mW 厚膜电阻 | 0603WAF1801T5E | UNI-ROYAL(厚声) | 0603 | 电阻类型：厚膜电阻 阻值：1.8kΩ 精度：±1% 功率：100mW 工作电压：75V 温度系数：±100ppm/℃ 工作温度：-55℃~+155℃ | 电阻 | C4177 | https://item.szlcsc.com/4584.html | 现货 | 4小时内发货 | 100 | 5000 | 613700 | 100 | 0.00891 | 0 | 0.89
 |  | 0603R | 3.3K |  | 39 | 贴片 电阻器 | R36 | 1 | 系统匹配 | 3.3kΩ ±1% 100mW 厚膜电阻 | 0603WAF3301T5E | UNI-ROYAL(厚声) | 0603 | 电阻类型：厚膜电阻 阻值：3.3kΩ 精度：±1% 功率：100mW 工作电压：75V 温度系数：±100ppm/℃ 工作温度：-55℃~+155℃ | 电阻 | C22978 | https://item.szlcsc.com/23705.html | 现货 | 4小时内发货 | 100 | 5000 | 791500 | 100 | 0.010395 | 0 | 1.04
 |  | 1206R | 430K |  | 40 | 贴片 电阻器 | R38, R44 | 2 | 系统匹配 | 厚膜电阻 430kΩ ±1% 250mW | RC1206FR-07430KL | YAGEO(国巨) | 1206 | 电阻类型：厚膜电阻 阻值：430kΩ 精度：±1% 功率：250mW 工作电压：200V 温度系数：±100ppm/℃ 工作温度：-55℃~+155℃ | 电阻 | C488851 | https://item.szlcsc.com/498547.html | 现货 | 4小时内发货 | 100 | 5000 | 27000 | 100 | 0.0306 | 0 | 3.06
 |  | 1206R | 190K |  | 41 | 贴片 电阻器 | R39, R40, R45, R46 | 4 | 人工匹配 | 191kΩ ±1% 250mW 厚膜电阻 | FRC1206F1913TS | FOJAN(富捷) | 1206 | 电阻类型：厚膜电阻 阻值：191kΩ 精度：±1% 功率：250mW 工作电压：200V 温度系数：±100ppm/℃ 工作温度：-55℃~+155℃ | 电阻 | C2930412 | https://item.szlcsc.com/3267345.html | 现货 | 4小时内发货 | 100 | 5000 | 16900 | 100 | 0.0197 | 0 | 1.97
 |  | R0603 | 1M |  | 42 | 贴片 电阻器 | R64 | 1 | 系统匹配 | 1MΩ ±1% 100mW 厚膜电阻 | 0603WAF1004T5E | UNI-ROYAL(厚声) | 0603 | 电阻类型：厚膜电阻 阻值：1MΩ 精度：±1% 功率：100mW 工作电压：75V 温度系数：±100ppm/℃ 工作温度：-55℃~+155℃ | 电阻 | C22935 | https://item.szlcsc.com/23662.html | 现货 | 4小时内发货 | 100 | 5000 | 454400 | 100 | 0.009 | 0 | 0.90
 |  | 0603R | 18K |  | 43 | 贴片 电阻器 | R67, R81 | 2 | 系统匹配 | 18kΩ ±1% 100mW 厚膜电阻 | 0603WAF1802T5E | UNI-ROYAL(厚声) | 0603 | 电阻类型：厚膜电阻 阻值：18kΩ 精度：±1% 功率：100mW 工作电压：75V 温度系数：±100ppm/℃ 工作温度：-55℃~+155℃ | 电阻 | C25810 | https://item.szlcsc.com/26553.html | 现货 | 4小时内发货 | 100 | 5000 | 207400 | 100 | 0.008514 | 0 | 0.85
 |  | 0603R | 330R |  | 44 | 贴片 电阻器 | R68, R75, R82, R87 | 4 | 系统匹配 | 330Ω ±1% 100mW 厚膜电阻 | 0603WAF3300T5E | UNI-ROYAL(厚声) | 0603 | 电阻类型：厚膜电阻 阻值：330Ω 精度：±1% 功率：100mW 工作电压：75V 温度系数：±100ppm/℃ 工作温度：-55℃~+155℃ | 电阻 | C23138 | https://item.szlcsc.com/23865.html | 现货 | 4小时内发货 | 100 | 5000 | 86900 | 100 | 0.0097 | 0 | 0.97
 |  | 0603R | 4.99K |  | 45 | 贴片 电阻器 | R78, R80 | 2 | 系统匹配 | 4.99kΩ ±1% 100mW 厚膜电阻 | 0603WAF4991T5E | UNI-ROYAL(厚声) | 0603 | 电阻类型：厚膜电阻 阻值：4.99kΩ 精度：±1% 功率：100mW 工作电压：75V 温度系数：±100ppm/℃ 工作温度：-55℃~+155℃ | 电阻 | C23046 | https://item.szlcsc.com/23773.html | 现货 | 4小时内发货 | 100 | 5000 | 743000 | 100 | 0.0103 | 0 | 1.03
 |  | 0603R | 5.1K |  | 46 | 贴片 电阻器, [NoValue] | R85, R132, R145, RP1, RP2 | 5 | 系统匹配 | 5.1kΩ ±1% 100mW 厚膜电阻 | 0603WAF5101T5E | UNI-ROYAL(厚声) | 0603 | 电阻类型：厚膜电阻 阻值：5.1kΩ 精度：±1% 功率：100mW 工作电压：75V 温度系数：±100ppm/℃ 工作温度：-55℃~+155℃ | 电阻 | C23186 | https://item.szlcsc.com/23913.html | 现货 | 4小时内发货 | 100 | 5000 | 7083500 | 100 | 0.0096 | 0 | 0.96
 |  | 1206R | 150K |  | 47 | 贴片 电阻器 | R96, R119 | 2 | 系统匹配 | 150kΩ ±5% 250mW 厚膜电阻 | FRC1206J154 TS | FOJAN(富捷) | 1206 | 电阻类型：厚膜电阻 阻值：150kΩ 精度：±5% 功率：250mW 工作电压：200V 温度系数：±100ppm/℃ 工作温度：-55℃~+155℃ | 电阻 | C2907431 | https://item.szlcsc.com/3180944.html | 现货 | 4小时内发货 | 100 | 5000 | 530000 | 100 | 0.0171 | 0 | 1.71
 |  | 1206R | 100K |  | 48 | 贴片 电阻器 | R97, R98, R120, R121 | 4 | 系统匹配 | 100kΩ ±1% 250mW 厚膜电阻 | FRC1206F1003TS | FOJAN(富捷) | 1206 | 电阻类型：厚膜电阻 阻值：100kΩ 精度：±1% 功率：250mW 工作电压：200V 温度系数：±100ppm/℃ 工作温度：-55℃~+155℃ | 电阻 | C2907368 | https://item.szlcsc.com/3180881.html | 现货 | 4小时内发货 | 100 | 5000 | 892000 | 100 | 0.0222 | 0 | 2.22
 |  | 2512R | 51R |  | 49 | 贴片 电阻器 | R99, R100, R101, R105, R106, R116, R117, R118, R125, R126 | 10 | 系统匹配 | 51Ω ±5% 1W 厚膜电阻 | 25121WJ0510T4E | UNI-ROYAL(厚声) | 2512 | 电阻类型：厚膜电阻 阻值：51Ω 精度：±5% 功率：1W 工作电压：200V 温度系数：±100ppm/℃ 工作温度：-55℃~+155℃ | 电阻 | C25490 | https://item.szlcsc.com/26233.html | 现货 | 4小时内发货 | 20 | 4000 | 41760 | 100 | 0.1515 | 0 | 15.15
 |  | 1206R | 510R |  | 50 | 贴片 电阻器 | R102, R103, R104, R140, R142, R144 | 6 | 系统匹配 | 510Ω ±5% 250mW 厚膜电阻 | 1206W4J0511T5E | UNI-ROYAL(厚声) | 1206 | 电阻类型：厚膜电阻 阻值：510Ω 精度：±5% 功率：250mW 工作电压：200V 温度系数：±100ppm/℃ 工作温度：-55℃~+155℃ | 电阻 | C25386 | https://item.szlcsc.com/26129.html | 现货 | 4小时内发货 | 100 | 5000 | 217100 | 100 | 0.020295 | 0 | 2.03
 |  | 1206R | 51K 1% |  | 51 | 贴片 电阻器 | R107, R112, R115 | 3 | 系统匹配 | 51kΩ ±1% 250mW 厚膜电阻 | FRC1206F5102TS | FOJAN(富捷) | 1206 | 电阻类型：厚膜电阻 阻值：51kΩ 精度：±1% 功率：250mW 工作电压：200V 温度系数：±100ppm/℃ 工作温度：-55℃~+155℃ | 电阻 | C2933722 | https://item.szlcsc.com/3279824.html | 现货 | 4小时内发货 | 100 | 5000 | 462500 | 100 | 0.0207 | 0 | 2.07
 |  | 1206R | 36R |  | 52 | 贴片 电阻器 | R108, R109, R123, R124 | 4 | 系统匹配 | 36Ω ±1% 250mW 厚膜电阻 | FRC1206F36R0TS | FOJAN(富捷) | 1206 | 电阻类型：厚膜电阻 阻值：36Ω 精度：±1% 功率：250mW 工作电压：200V 温度系数：±100ppm/℃ 工作温度：-55℃~+155℃ | 电阻 | C2907385 | https://item.szlcsc.com/3180898.html | 现货 | 4小时内发货 | 100 | 5000 | 34400 | 100 | 0.0201 | 0 | 2.01
 |  | 1206R | 5.1K |  | 53 | 贴片 电阻器 | R134 | 1 | 系统匹配 | 5.1kΩ ±1% 250mW 厚膜电阻 | 1206W4F5101T5E | UNI-ROYAL(厚声) | 1206 | 电阻类型：厚膜电阻 阻值：5.1kΩ 精度：±1% 功率：250mW 工作电压：200V 温度系数：±100ppm/℃ 工作温度：-55℃~+155℃ | 电阻 | C26033 | https://item.szlcsc.com/26776.html | 现货 | 4小时内发货 | 100 | 5000 | 323100 | 100 | 0.023562 | 0 | 2.36
 |  | 1206R | 20R |  | 54 | 贴片 电阻器 | R146, R147, R148, R149 | 4 | 系统匹配 | 20Ω ±5% 250mW 厚膜电阻 | FRC1206J200 TS | FOJAN(富捷) | 1206 | 电阻类型：厚膜电阻 阻值：20Ω 精度：±5% 功率：250mW 工作电压：200V 温度系数：±100ppm/℃ 工作温度：-55℃~+155℃ | 电阻 | C2907454 | https://item.szlcsc.com/3180967.html | 现货 | 4小时内发货 | 100 | 5000 | 640000 | 100 | 0.016 | 0 | 1.60
 |  | 0603R | 200R |  | 55 | 贴片 电阻器 | R_Ddj1 | 1 | 系统匹配 | 200Ω ±1% 100mW 厚膜电阻 | 0603WAF2000T5E | UNI-ROYAL(厚声) | 0603 | 电阻类型：厚膜电阻 阻值：200Ω 精度：±1% 功率：100mW 工作电压：75V 温度系数：±100ppm/℃ 工作温度：-55℃~+155℃ | 电阻 | C8218 | https://item.szlcsc.com/8708.html | 现货 | 4小时内发货 | 100 | 5000 | 1230200 | 100 | 0.009702 | 0 | 0.97
 |  | 0603R | 1.1K |  | 56 | 贴片 电阻器 | R_Ddj2 | 1 | 系统匹配 | 1.1kΩ ±1% 100mW 厚膜电阻 | FRC0603F1101TS | FOJAN(富捷) | 0603 | 电阻类型：厚膜电阻 阻值：1.1kΩ 精度：±1% 功率：100mW 工作电压：75V 温度系数：±100ppm/℃ 工作温度：-55℃~+155℃ | 电阻 | C2906975 | https://item.szlcsc.com/3180488.html | 现货 | 4小时内发货 | 100 | 5000 | 517500 | 100 | 0.0059 | 0 | 0.59
 |  | SOP-10 | LV8548MC |  | 57 | 步进电机驱动芯片 | U1 | 1 | 人工匹配 | 16V电机驱动芯片 | LV8548MC-AH | onsemi(安森美) | SOIC-10-1mm | 控制电压：4V~16V 输出电流：1A 驱动类型：双极驱动 步长细分：2；1 集成开关：是 导通电阻：1Ω 工作温度：-30℃~+85℃ | 电机驱动芯片 | C19950 | https://item.szlcsc.com/20659.html | 现货 | 4小时内发货 | 1 | 2500 | 363 | 1 | 4.96 | 0 | 4.96
 |  | SOT-223 | 1117-5 |  | 58 | 线性稳压芯片 | U2 | 1 | 系统匹配 | 5V 1A 12V | 1117-5 | IDCHIP(英锐芯) | SOT-223 | 输出类型：固定 工作电压：12V 输出电压：5V 输出电流：1A 电源纹波抑制比(PSRR)：75dB@(120Hz) 压差：1.3V@(1A) 静态电流(Iq)：10mA 噪声：0.003%Vout 功能特性：过流保护；热关断 工作温度：-40℃~+125℃@(Tj) 输出极性：正极 输出通道数：1 | 电源管理 | C5125089 | https://item.szlcsc.com/5722230.html | 现货 | 4小时内发货 | 10 | 2500 | 3690 | 10 | 0.4244 | 0 | 4.24
 |  | LQFP-48 | BAT32G139 LQFP48 |  | 59 | 单片机 | U3 | 1 | 无法匹配
 |  | TO-252 | LM317 |  | 60 | 线性稳压 | U4 | 1 | 系统匹配 | 1.2V~37V 1.5A 40V | LM317 | CJ(江苏长电/长晶) | TO-252-2L | 输出类型：可调 工作电压：40V 输出电压：1.2V~37V 输出电流：1.5A 压差：5V@(500mA) 功能特性：过流保护；短路保护；热关断 工作温度：0℃~+125℃@(Tj) 输出极性：正极 输出通道数：1 | 电源管理 | C77880 | https://item.szlcsc.com/79014.html | 现货 | 4小时内发货 | 5 | 2500 | 7550 | 10 | 1.5614 | 0 | 15.61
 |  | SOP-8 | UC3845 |  | 61 | 电源芯片 | U5 | 1 | 人工匹配 | 固定频率电流模式PWM控制器 | UC3845B | UMW(友台半导体) | SOP-8 | 开关频率：50kHz 工作温度：0℃~+70℃@(TA) 输出通道数：1 拓扑结构：升压式；反激式 静态电流(Iq)：17mA 开关管(内置/外置)：外置 输出类型：可调 | 电源管理 | C347460 | https://item.szlcsc.com/324120.html | 现货 | 4小时内发货 | 5 | 2500 | 13570 | 10 | 1.0532 | 0 | 10.53
 |  | SOP-8 | MCP602 |  | 62 | AMP 0.3V/uS | U6 | 1 | 人工匹配 | 单电源CMOS运算放大器 | MCP602T-I/SN | MICROCHIP(美国微芯) | SOIC-8 | 放大器数：2 最大电源宽度(Vdd-Vss)：7V 轨到轨：轨到轨输出 增益带宽积(GBW)：2.8MHz 输入失调电压(Vos)：1mV 输入失调电压温漂(Vos TC)：2.5uV/℃ 压摆率(SR)：4.5V/us 输入偏置电流(Ib)：20pA 输入失调电流(Ios)：1pA 输入电压噪声密度(eN)：29nV/√Hz@1kHz 共模抑制比(CMRR)：90dB 静态电流(Iq)：230uA 输出电流：22mA 工作温度：-40℃~+85℃ 单电源电压：2.7V~6V 功能特性：内置补偿；ESD保护 | 运算放大器/比较器 | C360037 | https://item.szlcsc.com/334817.html | 现货 | 4小时内发货 | 1 | 3300 | 13816 | 10 | 2.32 | 0 | 23.20
 |  | SOP-8 | LM358 |  | 63 | AMP 0.3V/uS | U7 | 1 | 人工匹配 | 双运算放大器 | LM358PWR(UMW) | UMW(友台半导体) | TSSOP-8 | 放大器数：2 最大电源宽度(Vdd-Vss)：36V 增益带宽积(GBW)：1.1MHz 输入失调电压(Vos)：5mV 输入失调电压温漂(Vos TC)：7uV/℃ 压摆率(SR)：600V/ms 输入偏置电流(Ib)：45nA 输入失调电流(Ios)：3nA 输入电压噪声密度(eN)：55nV/√Hz@1kHz 共模抑制比(CMRR)：85dB 输入失调电流温漂(Ios TC)：10pA/℃ 静态电流(Iq)：500uA 输出电流：40mA 工作温度：0℃~+70℃ 单电源电压：300mV~36V 双电源电压(Vee~Vcc)：-16V~16V | 运算放大器/比较器 | C41367195 | https://item.szlcsc.com/43118568.html | 现货 | 4小时内发货 | 5 | 4000 | 3910 | 10 | 0.477312 | 0 | 4.77
 |  | SOT23-5 | LM321 |  | 64 | 运算放大器 | U8 | 1 | 系统匹配 | 丝印A63A 增益带宽(GBP)1.2MHZ VIO:5mV LM321 丝印A63A | LM321 | MSKSEMI(美森科) | SOT-23-5 | 放大器数：1 最大电源宽度(Vdd-Vss)：36V 增益带宽积(GBW)：1.2MHz 输入失调电压(Vos)：5mV 输入偏置电流(Ib)：250nA 输入失调电流(Ios)：50nA 共模抑制比(CMRR)：80dB 静态电流(Iq)：500uA 工作温度：0℃~+70℃ 单电源电压：3V~36V 双电源电压(Vee~Vcc)：-18V~18V 功能特性：内置补偿 丝印A63A | 运算放大器/比较器 | C5252901 | https://item.szlcsc.com/5971202.html | 现货 | 4小时内发货 | 10 | 3000 | 80750 | 10 | 0.3299 | 0 | 3.30
 |  | LSOP6 | LTV-341P-H |  | 65 | 光耦 | U10, U12, U13, U14 | 4 | 人工匹配 | 采用拉伸型SO6封装、具备轨到轨输出电压的4.0 A输出电流IGBT栅极驱动光电耦合器 | LTV-341P-TA1-H | LITEON(光宝) | SO-6 | 负载类型：MOSFET；IGBT CMTI(kV/us)：35kV/us 驱动侧工作电压：15V~30V 传播延迟 tpHL：200ns 传播延迟 tpLH：200ns 隔离电压(Vrms)：5kV 耗散功率(Pd)：745mW 工作温度：-40℃~+105℃ 正向压降(Vf)：1.37V 直流反向耐压(Vr)：5V 下降时间(tf)：35ns 上升时间(tr)：35ns 功能特性：轨到轨输出；带滞后的欠压锁定 | 光耦 | C48542905 | https://item.szlcsc.com/50803972.html | 订货 | 预估7-10个工作日 | 1 | 1000 | 5 | 40 | 3.12 | 0 | 124.80
 |  | SOP-8 | LM2903 |  | 66 | 比较器/运算放大器 | U11 | 1 | 系统匹配 | 低功耗双电压比较器 | LM2903 | Slkor(萨科微) | SOP-8 | 比较器数：双路 输入失调电压(Vos)：1mV 输入偏置电流(Ib)：25nA 输出模式：MOS；CMOS；ECL；DTL；TTL 静态电流(Iq)：400uA 工作温度：-40℃~+125℃ 最大电源宽度(Vdd-Vss)：36V 单电源：2V~36V 双电源(Vee ~ Vcc)：-18V~-1V；1V~18V 输入失调电流(Ios)：5nA 响应时间(tr)：1.3us | 运算放大器/比较器 | C2999981 | https://item.szlcsc.com/3479121.html | 现货 | 4小时内发货 | 5 | 2500 | 1585 | 10 | 0.9548 | 0 | 9.55
 |  | YY-1 | 8M |  | 67 | 晶振 | Y1 | 1 | 人工匹配 | YSX531SL 8MHZ 4P 5032 20PF ±10PPM -40~85℃ (±20PPM) | XL1EL89CSI-111YLC-8M | YXC(扬兴晶振) | SMD5032-4P | 晶振类型：贴片晶振 频率：8MHz 常温频差：±10ppm 负载电容：20pF 频率稳定度：±20ppm 工作温度：-40℃~+85℃ | 振荡器/谐振器 | C7471624 | https://item.szlcsc.com/8526920.html | 现货 | 4小时内发货 | 5 | 1000 | 12305 | 10 | 1.3915 | 0 | 13.92
 |  | SOD-123 | 15V |  | 68 | 贴片 稳压二极管 | Z1, Z2, Z3 | 3 | 系统匹配 | 表面贴装齐纳二极管 | BZT52C15 | R+O(宏嘉诚) | SOD-123 | 二极管配置：1个独立式 稳压值(标称值)：15V 反向电流(Ir)：100nA 稳压值(范围)：14.25V~15.75V 耗散功率(Pd)：350mW 阻抗(Zzt)：30Ω 阻抗(Zzk)：200Ω 工作结温范围：-55℃~+150℃ | 二极管 | C19077412 | https://item.szlcsc.com/20275497.html | 现货 | 4小时内发货 | 50 | 3000 | 426500 | 50 | 0.1007 | 0 | 5.04

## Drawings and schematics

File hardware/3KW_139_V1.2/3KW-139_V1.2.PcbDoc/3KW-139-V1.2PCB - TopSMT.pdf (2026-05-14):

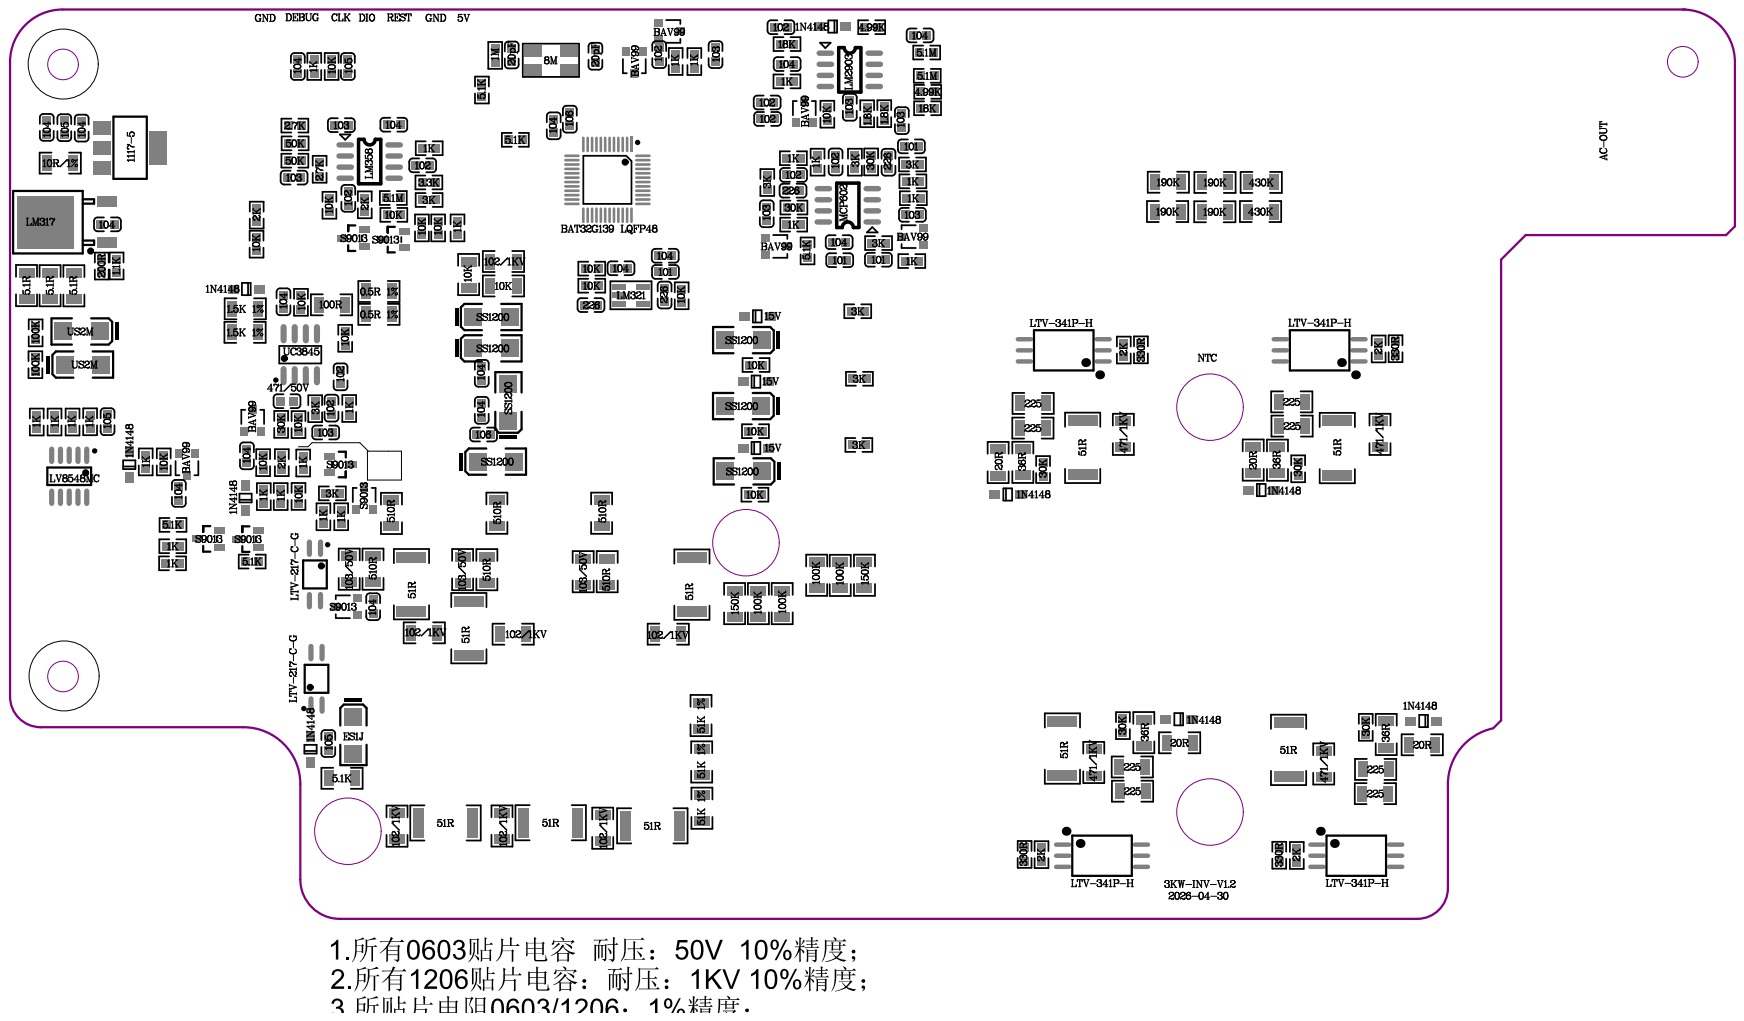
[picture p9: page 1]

Comment | Description | Designator | Footprint | LibRef | Quantity

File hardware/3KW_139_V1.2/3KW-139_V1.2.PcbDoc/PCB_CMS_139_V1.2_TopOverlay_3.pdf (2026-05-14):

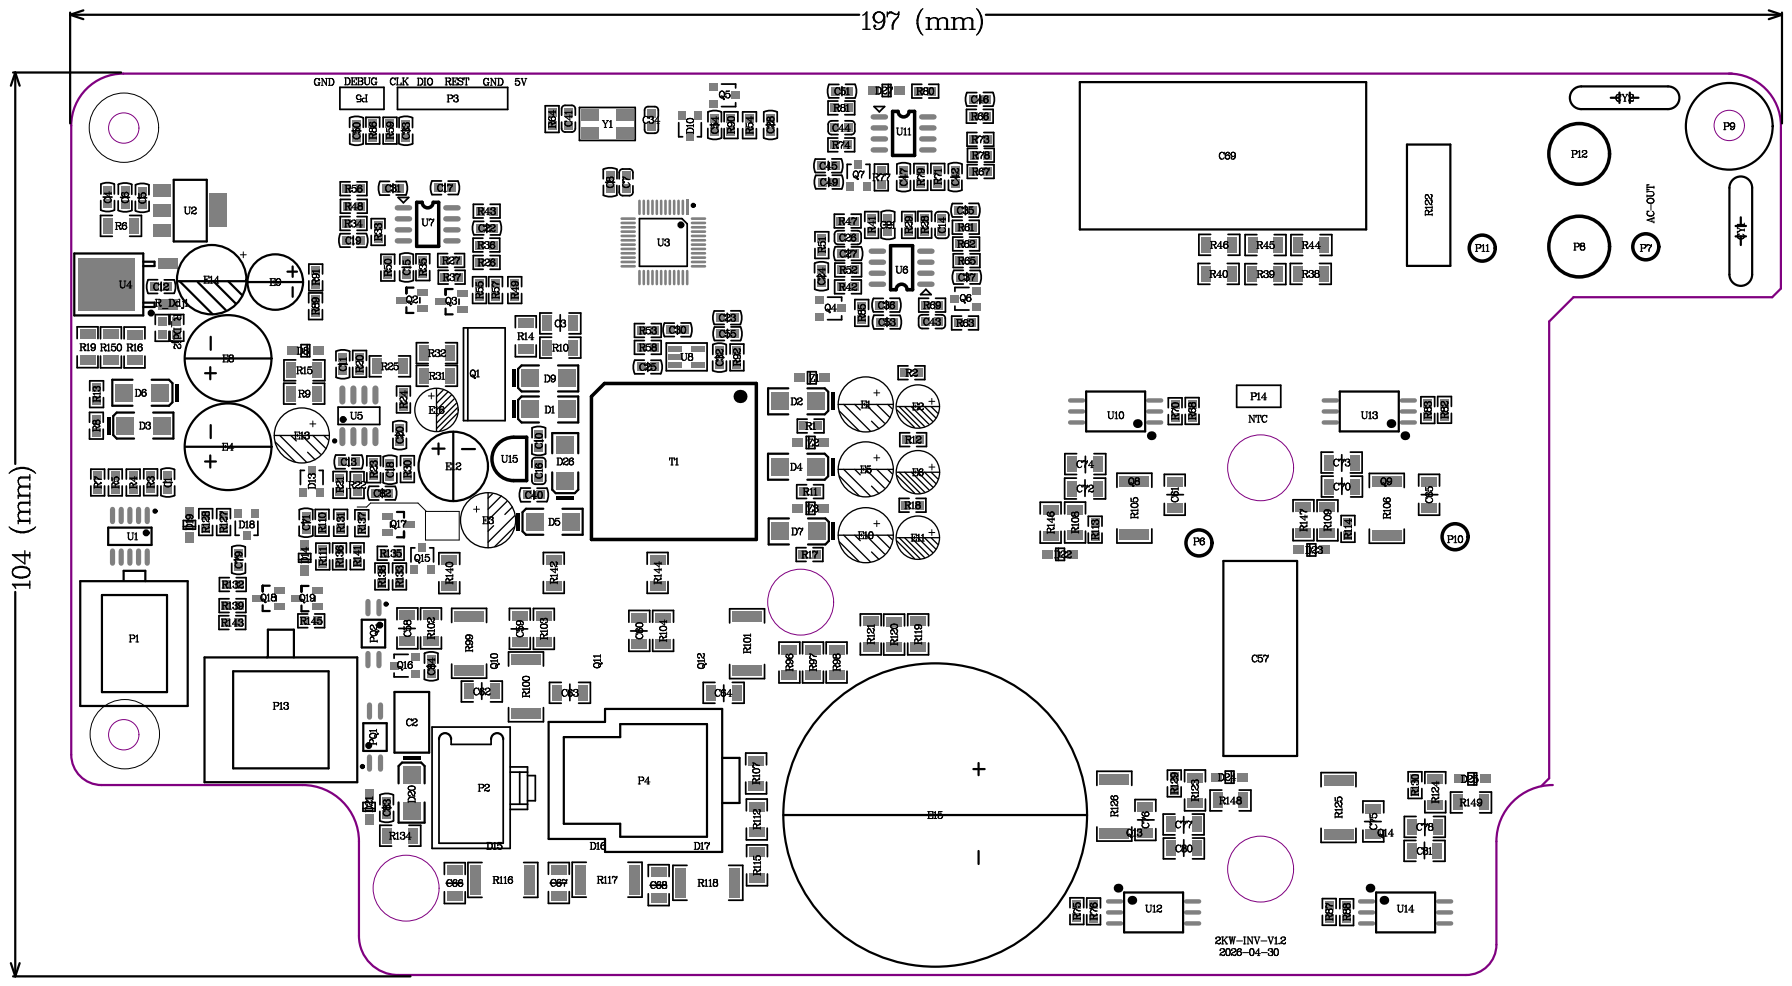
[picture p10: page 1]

Comment | Description | Designator | Footprint | LibRef | Quantity
105/25V 20% | 贴片 无极性电容 | C1, C6, C33 | 0603c | C_SMD | 3
104J/100V | CBB无极性电容 | C2 | 104/100V | CAPACITOR_CBB | 1
102/1KV 20% | 贴片 无极性电容 | C3, C62, C63, C64, | 1206C | C_SMD | 7
104/25V 20% | 贴片 无极性电容 | C4, C5, C8, C10, C10603c | | C_SMD | 15
106/25V 20% | 贴片 无极性电容 | C7 | 0603c | C_SMD | 1
471/50V 20% | 贴片 无极性电容 | C13 | 0603C | C_SMD | 1
226/25V 20% | 贴片 无极性电容 | C14, C25, C27, C32 | 0603c | C_SMD | 4
102/25V 20% | 贴片 无极性电容 | C15, C18, C20, C210603c | | C_SMD | 8
103/25V 20% | 贴片 无极性电容 | C19, C24, C28, C310603c | | C_SMD | 6
20pF/0603 | Cap | C34, C41 | C0603 | CAP-SMD | 2
101/25V 20% | 贴片 无极性电容 | C35, C43, C53, C55 | 0603c | C_SMD | 4
106/10V 20% | 贴片 无极性电容 | C40 | 0603c | C_SMD | 1
103/25V 10% | 贴片 无极性电容 | C42, C47 | 0603c | C_SMD | 2
102/25V 10% | 贴片 无极性电容 | C45, C51 | 0603c | C_SMD | 2
104/25V 10% | 贴片 无极性电容 CBB无极性电容 | C46 C57 | 0603c 105/400V-3 | C_SMD CAPACITOR_CBB | 1 105/400V 1
103/50V 20% | 贴片 无极性电容 | C58, C59, C60 | 1206C | C_SMD | 3
NC/471/1KV 20% | 贴片 无极性电容 | C61, C65, C75, C76 | 1206C | C_SMD | 4
106/630V | CBB无极性电容 | C69 | 106/400V | CAPACITOR_CBB | 1
225/50V 20% | 贴片 无极性电容 | C70, C72, C73, C741206C | | C_SMD | 8
105/25V 20% | 贴片 无极性电容 | C83 | 1206C | C_SMD | 1
104/25V 20% | 贴片 无极性电容 | C84 | 1206C | C_SMD | 1
Y1V400V222M | 贴片 无极性电容 | CY1, CY2 | Y1V400 | C_SMD | 2
SS1200 | 贴片 二极管 | D1, D2, D4, D5, D7, | SMA -AK | D_SMD | 7
US2M | 贴片 二极管 | D3, D6 | SMA - AK | D_SMD | 2
1N4148 | 贴片 二极管 贴片串联双二极管 egD10 , D13, D18, Q4, | D8, D14, D19, D21, | SOD-123F SO T-23 | D_SMD D2-串联,BAV99 | 9 BAV99 7
BYC15-600PQ | | D15, D16, D17 | TO-220-AC - S | DIODE TO-220 | 3
ES1J | 贴片 二极管 | D20 | SOD-123F | D_SMD | 1
47uF/35V | 直插 电解电容 | E1, E3, E5, E10, E13 | ECAP-6.3*11 | E | 5
22uF/25V | 直插 电解电容 直插 电解电容 | E2, E6, E11, E16 E4, E8 | ECAP-5*11 10*16 | E E | 4 220uF/50V 2
220uF/16V | 直插 电解电容 | E9 | 6.3*11 | E | 1
220uF/35V | 直插 电解电容 | E12 | 8*12 | E | 1
220uF/35V | 直插 电解电容 | E14 | EC08F350 | E | 1
2200uF/250V 35*4 | 直插电解电 容 Inductor Header, 4-Pin | E15 L1, L2 P1 | 1000uF/250V L45*45-1-1 P4-2.8 | E Inductor Header 4 | 1 S157125铁硅铝 2 Header 4 1
CON2 | | P2 | DJ7021A-2.8-11 | CON2 | 1
CON5 | Header, 5-Pin | P3 | HDR1X5 | Header 5 | 1
CON3 | | P4 | DJ3071A-6.3-11 | CON3 | 1
| Connector, 2Pin | P5 | HDR1X2 | CON2P | 1
CON1 | | P6, P7, P10, P11 | HOLE1.0 | CON1 | 4
CON1 | | P8, P12 | HOLE2.5 | CON1 | 2
CON1 | | P9 | HOLE1.6 | CON1 | 1
Header 6 | Header, 5-Pin | P13 | P6-2.8 | Header 6 | 1
CON2 | | P14 | HDR1X2 | CON2 | 1
LTV-217-C-G | 光藕-PC817,PC357 | PQ1, PQ2 | SOP-4-P1.27 | OPTO-817 | 2
UF640L | MOSFET | Q1 | TO-220 | MOS-N | 1
S9013 | NPN | Q2, Q3, Q15, Q16, | S8050 | S8050 | 7
CMSG50N60CA | | Q8, Q9, Q13, Q14 | to-247-1-1 | IGBT | 4
JCT616C | | Q10, Q11, Q12 | TO-220-AB1 - S | TYN625 | 3
10K/1% | 贴片 电阻器 | R1, R8, R11, R13, R0603R | | R_SMD | 22
3K 1% | 贴片 电阻器 | R2, R12, R18 | 0603R | R_SMD | 3
1K 1% | 贴片 电阻器 | R3, R4, R5, R7 | 0603R | R_SMD | 4
10R/1% | 贴片 电阻器 | R6 | 0603R | R_SMD | 1
10K/1% | 贴片 电阻器 | R9, R10, R14, R15 | 1206R | R_SMD | 4
5.1R 1% | 贴片 电阻器 | R16, R19, R150 | 1206R | R_SMD | 3
30K 1% | 贴片 电阻器 | R21 | 0603R | R_SMD | 1
3K/1% | 贴片 电阻器 | R23, R26, R28, R510603R | | R_SMD | 7
100R/1% | 贴片 电阻器 | R25 | 0603R | R_SMD | 1
5.1M/1% | 贴片 电阻器 | R27, R66, R73 | 0603R | R_SMD | 3
30K/1% | 贴片 电阻器 | R29, R52, R113, R10603R | | R_SMD | 6
0.5R/1% | 贴片 电阻器 | R31, R32 | 1206R | R_SMD | 2
4.9K/1% | 贴片 电阻器 | R33, R56 | 0603R | R_SMD | 2
49.9K/1% | 贴片 电阻器 | R34, R48 | 0603R | R_SMD | 2
2K/1% | 贴片 电阻器 | R35, R70, R71, R760603R | | R_SMD | 9
3.3K/1% | 贴片 电阻器 | R36 | 0603R | R_SMD | 1
200K/1% | 贴片 电阻器 | R38, R44 | 1206R | R_SMD | 2
100K/1% | 贴片 电阻器 | R39, R40, R45, R461206R | | R_SMD | 8
1K/1% | 贴片 电阻器 | R41, R42, R43, R470603R | | R_SMD | 20
1M/0603 | SMD | R64 | R0603 | RES-SMD | 1
18K/1% | 贴片 电阻器 | R67, R81 | 0603R | R_SMD | 2
330R/1% | 贴片 电阻器 | R68, R75, R82, R87 | 0603R | R_SMD | 4
4.99K/1% | 贴片 电阻器 | R78, R80 | 0603R | R_SMD | 2
5.1K/1% | 贴片 电阻器 | R85, R132, R134, R10603R | | R_SMD | 4
150K/1% | 贴片 电阻器 | R96, R119 | 1206R | R_SMD | 2
51R/1% | 贴片 电阻器 | R99, R100, R101, R1206R | | R_SMD | 6
510R/1% | 贴片 电阻器 | R102, R103, R104, | 1206R | R_SMD | 6
NC/51R/1% | 贴片 电阻器 贴片 电阻器 | R105, R106, R125, R2512R R107, R112, R115 | 1206R | R_SMD R_SMD | 4 51K/1% 3
36R/1% | 贴片 电阻器 | R108, R109, R123, R1206R | | R_SMD | 4
0.01R | 贴片 电阻器 | R122 | 0.01R 5WS水泥电阻 R_SMD | | 1
20R/1% | 贴片 电阻器 | R146, R147, R148, R1206R | | R_SMD | 4
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

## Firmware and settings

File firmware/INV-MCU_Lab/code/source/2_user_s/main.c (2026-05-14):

/*****************************************************************************
@Description: main.c
@Author     : naiva
@Version    : 2025.09.17 
@History    : 2025.09.17  naiva  V2.0.1 创建
@Attention  ：
*****************************************************************************/
#include "sys_mcu_header.h"
#include "sys_state_machine.h"
#include "user_function.h"
/****************************************************************************/

__IO uint8_t system_1ms_count = 0;//1ms时钟周期在Main函数需两个周期，即 u16_System1msbit_count >=1
/*************************************************
Description: main
Input      : 
Return     : 
Others     : 主调用函数
*************************************************/

int main(void)
{
    //硬件配置初始化 
    Sys_HardConfigInit();
    while(1)
    {
        //获取状态机的状态            
        State_Context.ContextPtr( &State_Context );     

        //执行状态机对应的任务
        Sys_StateMachine_Task();
                
        //用户功能任务调用（LED、KEY、updata）
        User_CommonFunction();

        if(SysClockBase_ms.system_1ms == 1)    
            system_1ms_count ++;//1ms时钟周期在Main函数存在的周期计数

        if(system_1ms_count >= 2)
        {
            SysClockBase_ms.system_1ms = 0;		//1ms 时钟标记清零
            system_1ms_count =0;//1ms时钟周期在Main函数存在的周期计数值清零
        }
    }
   
}

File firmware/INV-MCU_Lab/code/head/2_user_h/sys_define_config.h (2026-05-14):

/*****************************************************************************
@Description: sys_define_config.h 系统配置头文件
@Author     : naiva
@Version    : 2025.09.17 
@History    : 2025.09.17  naiva  V2.0.1 创建
@Attention  ：
*****************************************************************************/


#ifndef __SYS_DEFINE_CONFIG_H
#define	__SYS_DEFINE_CONFIG_H

/***************************************************************************/
/*-------------------EPWM开关周期设置--------------------------------------*/
/***************************************************************************/
#define MCU_CLK 	                            (64000000L)			/* PWM timer frequency[Hz] */
//#define PWM_FREQ	                            (12000L)				/* frequency[Hz] 12000hz*/
#define PWM_FREQ	                            (19200L)		  /* frequency[Hz]*/

#define DEADTIME			                    ((int32_t)((1.8 * MCU_CLK)) / 1000000L)
#if 1
    //中心互补对称周期值
    #define PWM_PERIOD	                        ((int32_t)((int32_t)MCU_CLK  / (PWM_FREQ * 2)) + DEADTIME - 2)   //1/fk* (m+2–p)* 2
    #define PWM_PERIOD_HALF 	                (PWM_PERIOD >> 1)
#else
    //锯齿波周期值
    #define PWM_PERIOD	                        ((int32_t)((int32_t)MCU_CLK  / (PWM_FREQ )) -1)  //1/fk * (m+1) = period = 1/PWM_FREQ   =>  m + 1 = fk/PWM_FREQ  锯齿波   
    #define PWM_PERIOD_HALF 	                (PWM_PERIOD >> 1)
#endif

/***************************************************************************/

/***************************************************************************/
/*-------------------串口波特率设置----------------------------------------*/
/***************************************************************************/
#define UART0_BAUDRATE                          (250000)        //UART0波特率设定值   
#define UART1_BAUDRATE                          (250000)        //UART1波特率设定值 
/***************************************************************************/

/***************************************************************************/
/*-------------------工作模式设置------------------------------------------*/
/***************************************************************************/
#define  NORMAL_MODE                            (0)
#define  DEBUG_MODE                             (1)
#define  OPERATING_MODE                         (NORMAL_MODE)
/***************************************************************************/

/*-------------------VACOUT输出电压缓启使能--------------------------------*/
#define INV_SOFTWARE_DISABLE                        (0)
#define INV_SOFTWARE_ENABLE                         (1)              
#define INV_SOFTWARE_CTRL_SELECT                    (INV_SOFTWARE_DISABLE)//是否启用输出电压缓启功能 
/*------------------------------------------------------------------------------------*/
//逆变输出电压缓启动相关参数
/*------------------------------------------------------------------------------------*/
#define INV_SOFTWARE_STEP_VALUE                         (50)//AC缓启动时，幅值系数每次步进值
#define INV_SOFTWARE_SHIFT_VALUE                        ( 6)//AC缓启动时，幅值系数缩放移位值
#define INV_SOFTWARE_HOLD_INIT                          (450 << INV_SOFTWARE_SHIFT_VALUE)//放大后的幅值系数初始值

/***************************************************************************/
/*-------------------IO端口宏定义------------------------------------------*/
/***************************************************************************/
#define LED_RED_ON                              ( PORT->PSET6 = (1<<1) )
#define LED_RED_OFF                             ( PORT->PCLR6 = (1<<1) )

#define LED_GREEN_ON                            ( PORT->PSET6 = (1<<0) )
#define LED_GREEN_OFF                           ( PORT->PCLR6 = (1<<0) )

//SCR：可控硅整流器（Silicon Controlled Rectifier）
#define INV_SCR_ENABLE                          ( PORT->PSET3 = (1<<0) )//宏定义输出控制 变量（整流器控制，“1”开启整流器）
#define INV_SCR_DISABLE                         ( PORT->PCLR3 = (1<<0) )//宏定义输出控制 变量（整流器控制，“0”关闭整流器）
#define INV_SCR_STATUS	                        (PORT_GetBit(PORT3,PIN0) >> 0)//


#define ECOMODE	 	                            (PORT_GetBit(PORT7,PIN4) >> 4) //节能模式
#define FAULT_RST	                            (PORT_GetBit(PORT3,PIN1) >> 1) //故障复位
#define FRESWITCH	                            (PORT_GetBit(PORT7,PIN1) >> 1)//逆变器频率选择，默认上拉输入(低电平有效)base_freq=1->50hz/0->60hz
/***************************************************************************/
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

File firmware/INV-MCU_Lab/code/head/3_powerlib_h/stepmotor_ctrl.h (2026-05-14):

/*****************************************************************************
@Description: stepmotor_ctrl.c 步进电机控制
@Author     : naiva
@Version    : 2025.09.17 
@History    : 2025.09.17  naiva  V2.0.1 创建
@Attention  ：
*****************************************************************************/
#ifndef __STEPMOTOR_CTRL_H_
#define __STEPMOTOR_CTRL_H_

#include "stdint.h"
#include "sys_define_config.h"

extern  unsigned short int Step_Driver_Signal_Buff[9];

#define Len_Power_Rpm		                                    (6)
#define CM_Pcv_BASE                                         (131)
#define P_GQ                                                (6)
//步进电机控制输出IO宏定义变量
#define StepA  PORTCbits.RC6   //宏定义输出控制 RC6变量（步进电机驱动A）
#define StepB  PORTCbits.RC7   //宏定义输出控制 RC7变量（步进电机驱动B）
#define StepC  PORTCbits.RC8   //宏定义输出控制 RC8变量（步进电机驱动C）
#define StepD  PORTCbits.RC9   //宏定义输出控制 RC9变量（步进电机驱动D）

/*------------------------------------------------------------------------------*/
/*------------------------------------------------------------------------------*/
#define  Motor_Step_Driver_Freq                             (2)
#define  CM_Engine_Pole_Pairs                               (9)
#define  CM_RPM_BASE_Value                                  (4600)
#define  CM_RPM_BASE                                        (114)  //4600   (4096 / 4600 * 128 = 114)
#define  R_GQ                                               (7)
#define  Protect_Idle_Rpm                                   ((2850L*CM_RPM_BASE)>>R_GQ)   //3720
#define  CM_Engine_Speed_RefMAX                             (( 4000UL * CM_RPM_BASE ) >> R_GQ)	//参考转速最大值限制
//13333
//   RPM =  (60 * f) / 9极对数
#define ECAP_VALUE_FREQ_LIMIT_UP                            (22200)//300hz   2571RPM     8M  1/8us      
#define ECAP_VALUE_FREQ_LIMIT_DOWN                          (12428)  // 	(1000000/(12428/8))*60/9  700Hz时的周期数       6000rpm      
/*-----------------------------------------------------------------------------*/
//#define CM_Engine_Speed_RefMAX  ((4000UL * CM_RPM_BASE) >> R_GQ) // 转速参考最大值

#define  Motor_Step_kp                                      (280)
#define  Motor_Step_ki                                      (55)
#define  Motor_Step_kd                                      (5)
#define  Motor_Period_Value                                 (170)
//#define Motor_Step_kp           (280)       // 比例系数
//#define Motor_Step_ki           (55)        // 积分系数
//#define Motor_Step_kd           (5)         // 微分系数
//#define Motor_Period_Value      (170)       // 控制周期值
/*-----------------------------------------------------------------------------*/
/*-----------------------------------------------------------------------------*/
#define  Motor_Step_ErrMax                                  (1500)
#define  Motor_Step_ErrMin                                  (-1500)
#define  Motor_Step_OutMax                                  (100)//60
#define  Motor_Step_OutMin                                  (-100)//-60
#define  Motor_Steady_State_Dot                             (4000)

//#define Motor_Step_ErrMax       (1500)      // 误差最大值
//#define Motor_Step_ErrMin       (-1500)     // 误差最小值
//#define Motor_Step_OutMax       (100)       // 输出最大值
//#define Motor_Step_OutMin       (-100)      // 输出最小值

/*------------------------------------------------------------------------------*/
/*------------------------------------------------------------------------------*/
#define  Forward_Driver_Motor                               (0) // 正转
#define  Inverse_Driver_Motor                               (1) // 反转
/*------------------------------------------------------------------------------*/
#define  Motor_Step_Static_MidNum                           (5000)
#define  Motor_Step_Num                                     (8)
#define  Motor_Step_Driection                               Forward_Driver_Motor    // 正转
/*------------------------------------------------------------------------------*/

/*------------------------------------------------------------------------------*/
/*------------------------------------------------------------------------------*/
typedef struct { 
                    int  ref;               
                    int  fdb;               
                    int  err;                   
                    int  err_n;                  
                    int  err_n2;
                    int  kp;                        
                    int  ki;                       
                    int  kd;                                        
                    int  errMax;                   
                    int  errMin;                      
                    int  outMax;               
                    int  outMin;              
                    int  out;                
              short int  stepNum;
              short int  stepDirection;
              short int  stepIndex;
              short int  stepStaticMidNum;
              short int  stepActiveNum;
     unsigned short int  periodCount;
     unsigned short int  periodValue;

     unsigned short int *Motor_Driver_Signal_Ptr;
  volatile unsigned int *Motor_Driver_Hard_Set_Ptr[1];
  volatile unsigned int *Motor_Driver_Hard_Clear_Ptr;
                void   (*PI_Calc)();	                // Pointer to calculation function
} StepMotor_Ctrl_t;

//typedef struct { 
//    int  ref;               // 转速参考值（给定值）
//    int  fdb;               // 转速反馈值（实际测量值）
//    int  err;               // 当前误差（ref - fdb）
//    int  err_n;             // 上次误差
//    int  err_n2;            // 上上次误差
//    int  kp;                // 比例系数
//    int  ki;                // 积分系数
//    int  kd;                // 微分系数
//    int  errMax;            // 误差上限
//    int  errMin;            // 误差下限
//    int  outMax;            // 输出上限
//    int  outMin;            // 输出下限
//    int  out;               // PID输出结果
//    short int  stepNum;     // 步进电机步数
//    short int  stepDirection; // 步进电机方向
//    short int  stepIndex;   // 步进电机索引
//    short int  stepStaticMidNum; // 静态中值
//    short int  stepActiveNum; // 活跃步数
//    unsigned short int  periodCount; // 周期计数
//    unsigned short int  periodValue; // 周期值
//    unsigned short int *Motor_Driver_Signal_Ptr; // 电机驱动信号指针
//    volatile unsigned int *Motor_Driver_Hard_Set_Ptr[1]; // 硬件设置指针
//    volatile unsigned int *Motor_Driver_Hard_Clear_Ptr; // 硬件清除指针
//    void   (*PI_Calc)();    // PID计算函数指针
//} StepMotor_Ctrl_t;

typedef StepMotor_Ctrl_t *StepMotor_handle;


/*-----------------------------------------------------------------------------
Default initalizer for the PARK object.
-----------------------------------------------------------------------------*/
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

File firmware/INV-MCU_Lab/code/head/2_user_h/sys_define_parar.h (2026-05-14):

/*****************************************************************************
@Description: sys_define_parar.h 系统参数定义头文件
@Author     : naiva
@Version    : 2025.09.17 
@History    : 2025.09.17  naiva  V2.0.1 创建
@Attention  ：
*****************************************************************************/

#ifndef __SYS_DEFINE_PARAR_H
#define __SYS_DEFINE_PARAR_H
#include "sys_define_config.h"




/***************************************************************************/
//虚拟阻抗系数
/***************************************************************************/
#define INV_VIRTUAL_RES                                     ( 0 )


/***************************************************************************/
/*VREF_AD校正值*/
/***************************************************************************/
#define COM_VREF_AD_CORRECT_UP                              (4296)
#define COM_VREF_AD_CORRECT_MID                             (4096)
#define COM_VREF_AD_CORRECT_DOWN                            (3896)

/***************************************************************************/
//电压开机校正值
/***************************************************************************/
#define COM_V_ACOUT_AD_CORRECT_UP                           ( 4296 )
#define COM_V_ACOUT_AD_CORRECT_MID                          ( 4096 )
#define COM_V_ACOUT_AD_CORRECT_DOWN                         ( 3896 )

/***************************************************************************/
//电感电流开机校正值
/***************************************************************************/    
#define COM_I_INDUC_AD_CORRECT_UP                           ( 4296 )
#define COM_I_INDUC_AD_CORRECT_MID                          ( 4096 )
#define COM_I_INDUC_AD_CORRECT_DOWN                         ( 3896 )
    

/***************************************************************************/
//按键监测参数设置
/***************************************************************************/
#define Key_Pro_Reset_Compare_Dot                           (0)
#define Key_Pro_Reset_Compare_Type                          E_EQUAL
#define Key_Pro_Reset_Delay_MaxCount                        (200)

#define Key_SW_ECO_Compare_Dot                              (0)
#define Key_SW_ECO_Compare_Type                             E_EQUAL
#define Key_SW_ECO_Delay_MaxCount                           (200)

#define Key_SW_FreqChoice_Compare_Dot                       (0)
#define Key_SW_FreqChoice_Compare_Type                      E_EQUAL
#define Key_SW_FreqChoice_Delay_MaxCount                    (200)
    
/***************************************************************************/
//开机检测温度参数设置
/***************************************************************************/
#define COM_START_CHECK_TEMP_UP_RES                         (2.240)//设定温度70℃对应NTC电阻值(KΩ)
#define COM_START_CHECK_TEMP_UP_BACK_RES                    (1.678)//设定温度80℃对应NTC电阻值(KΩ)
#define COM_START_CHECK_TEMP_UP                             (int32_t)((COM_START_CHECK_TEMP_UP_RES/(COM_START_CHECK_TEMP_UP_RES+HW_TEMP_DIVIDE_RES)*4096))  
#define COM_START_CHECK_TEMP_UP_BACK                        (int32_t)((COM_START_CHECK_TEMP_UP_BACK_RES/(COM_START_CHECK_TEMP_UP_BACK_RES+HW_TEMP_DIVIDE_RES)*4096)) 
#define COM_START_CHECK_TEMP_UP_TIME		                (700)//延时时间(ms)


/*------------------------------------------------------------------------------------*/
//辅助电源上下限参数设置
/*------------------------------------------------------------------------------------*/

#define COM_AUX_POWER_MAX                                   (15.0)//(V)
//#define COM_AUX_POWER_MIN                                   (9.9)
//#define COM_AUX_POWER_VALBACK                               (0.3)//保护使用的回差值
#define COM_AUX_POWER_MIN                                   (8.5) // 20251015
#define COM_AUX_POWER_VALBACK                               (0.5) // 20251015 保护使用的回差值
/***************************************************************************/
//开机检测辅助电源参数设置
/***************************************************************************/
#define COM_START_CHECK_AUX_POWER_UP                        (int32_t)( COM_AUX_POWER_MAX * 4096/COM_AUX_POWER_BASE)// 2048 辅助电源真是电压(V)*COM_REAL_AUXPOWER_SCAL   
#define COM_START_CHECK_AUX_POWER_UP_BACK                   (int32_t)((COM_AUX_POWER_MAX + COM_AUX_POWER_VALBACK) * 4096/COM_AUX_POWER_BASE)// 2116.3
#define COM_START_CHECK_AUX_POWER_UP_TIME		            (700)//延时时间(ms)

#define COM_START_CHECK_AUX_POWER_DN                        (int32_t)( COM_AUX_POWER_MIN * 4096/COM_AUX_POWER_BASE)	// 1228.8
#define COM_START_CHECK_AUX_POWER_DN_BACK                   (int32_t)((COM_AUX_POWER_MIN - COM_AUX_POWER_VALBACK) * 4096/COM_AUX_POWER_BASE)// 1160.5
#define COM_START_CHECK_AUX_POWER_DN_TIME			        (700)//延时时间(ms)
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

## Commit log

2026-05-14 Initial open-source release
    [3KW-139_V1.0PCB.PcbDoc, 3KW-139_V1.0_铝基板_IGBT.PcbDoc, 3KW-139_V1.2SchDoc.SchDoc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]
2026-06-04 Update something
    [3KW-139_V1.2SchDoc.SchDoc]
